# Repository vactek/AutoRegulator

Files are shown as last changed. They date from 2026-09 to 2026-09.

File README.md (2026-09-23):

# AutoRegulator

AutoRegulator is an Arduino Nano or NanoBLE powered suction regulator for vacbeds.
A relay is actuated based on a sensor and threshold - that's pretty much it.
It's designed to be inexpensive and easy to source parts for. 

It's very DIY - you could use it with a vacuum cleaner with a check valve, or a diaphragm pump.
This project is just in charge of switching a relay.

## WIP: TODO:
- finish sourcing links
- upload schematic and hardware build guide (maybe do a pcb, it's not that many wires to solder though)
- organize my 500 line main into separate files

## Features

- Automatic calibration to your elevation
- Settable suction level
- LED feedback

### NanoBLE only features

- Serial console with statistics
- coming soon? BLE functionality / [buttplug.io](https://github.com/buttplugio) integration (I have a separate working prototype, just have to integrate it)
- coming soon? pulsing/pattern playback functionality (may require additional hardware to increase venting rate)

### Safety features

This device isn't intended to be used alone, it's not safe, ***DO NOT*** do it.
We can't make any claims about safety, even if you build and use the project as intended.
In the rare case that something goes wrong, like, a lightning strike, we've tried to include as many safety features as reasonable:
  - shuts down on power loss or reset, which disables suction
  - requires external input (turn dial all the way to the left) upon reboot before starting
  - automatic shutdown if sensor read fails
  - automatic shutdown after 1 hour

...but you should not rely on any of these. Ever. This isn't enterprise industrial control software, it's DIY hardware, and ultimately, it's up to the operator of the machine to decide how to use this! *Even* having a supervisor may not be enough, and we actually recommend using [an entirely separate timer-controlled outlet](https://www.amazon.com/s?k=timer+controlled+outlet) in *addition*, to interrupt power to your pump after an hour.
(I'm not liable or responsible for the irresponsible use of this considerably irresponsible firmware written by idiots)

## Build Guide

### Electronics BOM with Sourcing (US)

 - Arduino Nano, or clone
 - Honeywell absolute pressure sensor breakout board
   - (preferred) Adafruit: https://www.adafruit.com/product/3965
   - (alternative) DigiKey: https://www.digikey.com/en/products/detail/adafruit-industries-llc/3965/9658071
   - (alternative, more expensive as shipping is bundled into price) Amazon: https://a.co/d/0icpQsJ6
 - Isolated relay module
   - (alternative) Amazon: https://a.co/d/0h9XaJEC
 - RGB Potentiometer
   - (preferred) Adafruit: https://www.adafruit.com/product/6387
   - (alternative) DigiKey: https://www.digikey.com/en/products/detail/adafruit-industries-llc/6387/27545875
   - If you'd like, you can use a plain linear rotary pot (10k ideally) and a single WS2812B-compatible LED
 - Solderable FR4 Protoboard - 70x90mm recommended
 - Female pin headers (optional, but makes swapping things out a lot easier while soldering)
 - 0.1uF ceramic capacitor (THT, optional, filter power input to relay board)

You may need some other things, such as:
 - Electrical tape
 - Pliers, screws
 - Soldering iron w/ fine solder
 - Wire (I used solid core 18AWG)
 - A screwdriver
 - And importantly, a wiring solution for whatever you connect the relay to. May require lever nuts, ferrules, etc.

### 3D Printed Parts (SLA)

- [Sensor to 3/16" tubing adapter](/models/AdafruitSensorToTubing.stl) (requires heatset inserts, and 2 2.5mmx8 SHCS screws)
- 3/16" tubing to PVC adapter (todo:link, other PVC size variants)
- 3/16" tubing break-out block

- You'll also want a case, but depending on where you mount the parts on the protoboard, it's going to be different.

### Assembly

- **NOTICE**: The Honeywell pressure sensor, and the breakout board by extension, is *extremely* fragile.
Even soldering the pin headers for too long can overexpose it to heat and cook it.
Giving it 5V on the 3Vo pin will instantly fry it.
Giving the regulator more than ~9V will instantly boil it.
SDA/SCL can accept at *most* whatever you give the regulator thanks to the level shifter.
Double check your wiring at every stage and before power on.

- **NOTICE**: AC Power is dangerous.

- Pinouts for supported boards

| Arduino Nano Pin | Arduino Nano33BLE Pin | Connect To | 
|---|---|---|
| A1 | A1 | Potentiometer center | 
| A2 | A2 | Neopixel Data In |
| A4 (SDA) | A4 (SDA) | Sensor SDA |
| A5 (SCL) | A5 (SCL) | Sensor SCL |
| A7 | A7 | Relay input |
| 5V | 3V3 | Potentiometer V+ |
| 5V | 3V3 | Neopixel VCC |
| 5V | 3V3 | Sensor Vin |
| Vin/VBUS | Vin/VBUS | Relay DC+ |
| GND | GND | Relay DC- |
| GND | GND | Sensor GND |
| GND | GND | Neopixel GND |
| GND | GND | Potentiometer V- |

---

| Relay Pin | Connect To |
|---|---|
| COM | User defined, e.g, AC neutral |
| NO | User defined, e.g, AC live |
| NC | **Nothing** |

---

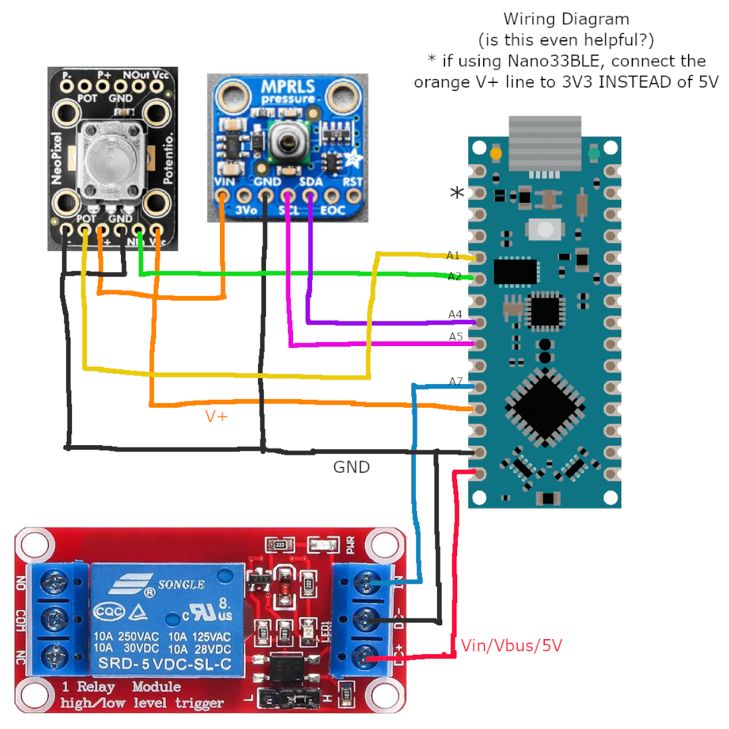
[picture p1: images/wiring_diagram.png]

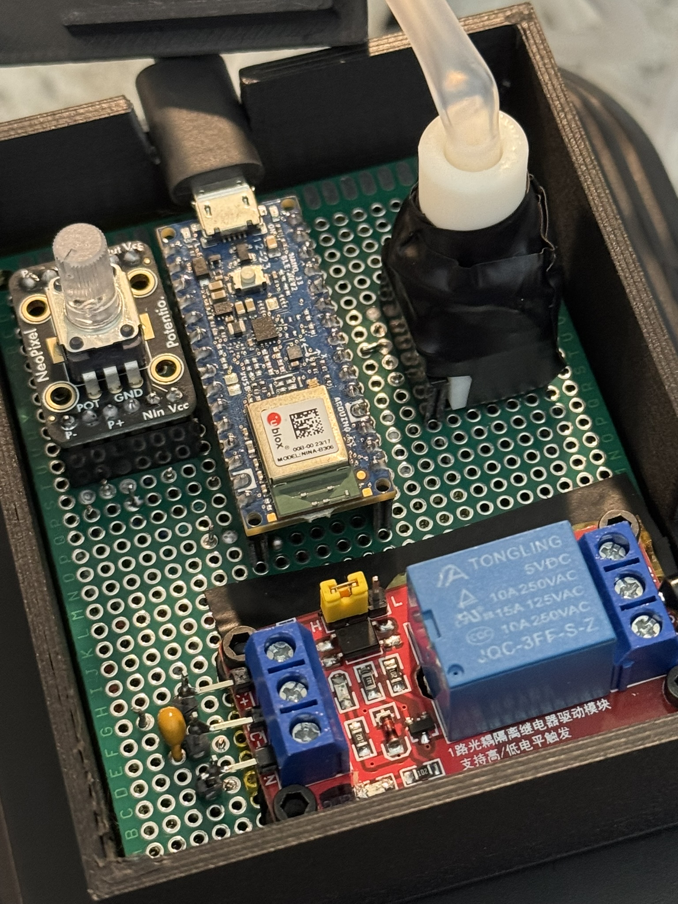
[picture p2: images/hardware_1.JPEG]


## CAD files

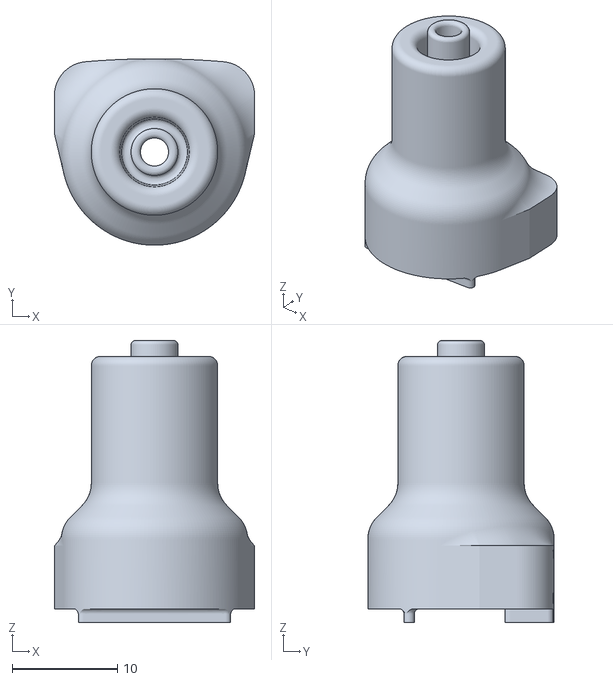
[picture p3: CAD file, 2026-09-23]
models/AdafruitSensorToTubing.stl
19.0 x 17.7 x 26.8

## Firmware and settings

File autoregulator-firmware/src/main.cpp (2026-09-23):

/**
  AutoRegulator Firmware for Arduino Nano / Nano33BLE
  
  We toggle a relay based on a sensor reading and threshold, set by a knob.

  2026
  
  Tip: Flash a DEV_ version to wait-for-serial

*/

#include <Arduino.h>
#include <Wire.h>
#include <Adafruit_MPRLS.h>
#include <Adafruit_NeoPixel.h>

#include "user_config.h"
#include "system_constants.h"

#include "app_debug.h"
#include "util.h"


// ### GLOBALS

// peripheral objects
Adafruit_NeoPixel g_neopixel(NUM_NEOPIXELS, PIN_NEOPIXEL, NEO_GRB + NEO_KHZ400);
Adafruit_MPRLS g_mpr25 = Adafruit_MPRLS(PIN_SENSOR_MANUAL_RESET, -1, MPR_PSI_MIN, MPR_PSI_MAX, MPR_factoryDefault_Omin, MPR_factoryDefault_Omax, MPR_Kfactor); // no rst/eoc

// vars
float calibration_ref_psi = PSI_ATMOSPHERIC;
float last_known_psi      = 0.0; // ONLY used for stats
// ONLY set this by enableSuction/disableSuction functions!
// ONLY read this for controlling LEDs!
bool isSuctionActive     = false;
float targetPressure     = 99999; // used by control system, AND for stats. units mbar
float potentiometerValue = 0.0;   // pot 0.0 - 1.0
// stats
uint32_t started_this_pull_at       = 0;    // if 0, we can assume we haven't started a pull down, but it's better to check isSuctionActive to be sure.
bool waiting_for_inital_pulldown    = true; // turns false the first time the target is reached
uint32_t first_pulldown_achieved_at = 0;
uint32_t this_pulldown_achieved_at  = 0; // also used for LED animation upon pulldown
// these vars are the number of counts spent "pulling down" a vacuum in the main loop
// and the total counts where the target pressure is met while in the main loop, respectively
// where one count occurs during one loop
uint32_t vac_duty_on_post_pulldown  = 0;
uint32_t vac_duty_off_post_pulldown = 0;

// elapsed-timers used by multiple functions
uint32_t time_of_last_mech_change = 0;
uint32_t time_since_last_mech_change() { return millis() - time_of_last_mech_change; }

// ### FUNCTIONS

void led_heartbeat() {
    // simple check if main loop is running. 0x20 -> brightness
    analogWrite(LED_BUILTIN, millis() % HEARTBEAT_PERIOD > (HEARTBEAT_PERIOD >> 1) ? 0x20 : LOW);
}

void configure_pins() {

    pinMode(LED_BUILTIN, OUTPUT);
    digitalWrite(LED_BUILTIN, LOW);

    pinMode(PIN_RELAY, OUTPUT);
    digitalWrite(PIN_RELAY, (MECHANICAL_ACTIVE_LEVEL == HIGH) ? LOW : HIGH);

    pinMode(PIN_NEOPIXEL, OUTPUT);
    pinMode(PIN_POTENTIOMETER, INPUT);

    // todo: dynamically (or statically if it's possible)
    // force the ADC resolution to 10 bits
    // in a way that works on all supported boards
}

bool userInputValid() {
    // true if an input is asserted; does not sample the adc, so you must call update_pot_val() first.
    return potentiometerValue > POT_LOWER_CUTOFF_PERCENT;
}

float get_single_pot_value() { 
    // just read the ADC, doesn't touch global state
    return mapfloat(analogRead(PIN_POTENTIOMETER), 0, AR_ADC_MAX, 0.0, 1.0); 
}

void disableSuction() {
    // (ideally) no effect if suction already disabled
    uint8_t state_prev = digitalRead(PIN_RELAY);
    uint8_t state_new  = (MECHANICAL_ACTIVE_LEVEL == HIGH) ? LOW : HIGH;
    digitalWrite(PIN_RELAY, state_new);
    isSuctionActive = false;
    if (state_new != state_prev) {
        time_of_last_mech_change = millis();
        started_this_pull_at     = 0;
    }
}

void disableSuctionFS() {
    // immediately disable suction, none of the fluff
    digitalWrite(PIN_RELAY, !(MECHANICAL_ACTIVE_LEVEL));
}

void enableSuction() {
    // no effect if suction already enabled
    // enables suction as soon as possible
    // only held up for mechanical wear reasons
    uint8_t state_prev = digitalRead(PIN_RELAY);
    uint8_t state_new  = (MECHANICAL_ACTIVE_LEVEL == HIGH) ? HIGH : LOW;

    if (state_new != state_prev) {
        while (time_since_last_mech_change() <= (float(MILLIS_PER_SEC) / MECHANICAL_MAX_HZ)) {
            // while in this spin, we still want to check the potentiometer in case the user turns it back off
            // don't replace this with !userInputValid, we actually have to poll it ourselves
            // the global isn't updated, and we don't want to take an average.
            if (get_single_pot_value() < POT_LOWER_CUTOFF_PERCENT) {
                disableSuction();
                return;
            }
        }
        time_of_last_mech_change = millis();
        started_this_pull_at     = time_of_last_mech_change;
    }
    digitalWrite(PIN_RELAY, state_new);
    isSuctionActive = true;
}

void update_pot_val() {
    // updates the global variable
    uint32_t running_total = 0;
    for (unsigned k = 0; k < POT_SAMPLE_SZ; k++) {
        running_total += analogRead(PIN_POTENTIOMETER);
        // let's not complicate it further, and pretend that analogRead is instantaneous
        delayMicroseconds((MICROS_PER_MILLI * POT_SAMPLE_DELAY) / POT_SAMPLE_SZ);
    }

    float avg          = running_total / POT_SAMPLE_SZ;
    potentiometerValue = mapfloat(avg, 0, AR_ADC_MAX, 0.0, 1.0);
}

void neopixel_show_i2c_rate_limited() {
    // calls g_neopixel.show but only if we didn't call it in the last 2ms
    // todo: the actual rate limit, lmao
    g_neopixel.show();
}

void neopixel_show_color(uint32_t c) {
    g_neopixel.fill(c);
    g_neopixel.setBrightness(LED_BRIGHTNESS_PERCENT * 0xFF);
    neopixel_show_i2c_rate_limited();
}

void neopixel_flash_color(uint32_t c) {
    // non-blockingly flash a color
    static unsigned period = MILLIS_PER_SEC / LED_RAPID_FLASH_HZ; // ms

    if ((millis() % period) > (period >> 1)) {
        g_neopixel.fill(c);
        g_neopixel.setBrightness(LED_BRIGHTNESS_PERCENT * 0xFF);
    } else {
        g_neopixel.clear();
    }
    neopixel_show_i2c_rate_limited();
}

void _on_fail(void) {
    // ! invoke with EXIT_FAILURE_FN() - NOT DIRECTLY !
    // function to run when something goes wrong.
    disableSuction();
    DEBUGLN(F("on_fail called, halting"));
    while (true) {
        neopixel_flash_color(COLOR_ERROR);
    }
}
#define EXIT_FAILURE_FN()                                                                                                                                                                                                                      \
    {                                                                                                                                                                                                                                          \
        disableSuctionFS();                                                                                                                                                                                                                    \
        TIMESTAMPLN();                                                                                                                                                                                                                         \
        _on_fail();                                                                                                                                                                                                                            \
    }

void periodicStatsPrint() {
#ifdef CAN_STORE_MANY_STRINGS
    static uint32_t loopcounter        = 0;
    static uint32_t time_of_last_print = 0;
    loopcounter++;
    if ((millis() - time_of_last_print) < PRINTERVAL) {
        return;
    }

    TIMESTAMPLN();

    DEBUG("> Superloop ARR: ");
    DEBUG(float(loopcounter) / ((millis() - time_of_last_print) / float(MILLIS_PER_SEC)));
    DEBUGLN(" Hz");
    loopcounter = 0;

    DEBUG("> Raw pressure (Psi): ");
    DEBUGLN(last_known_psi, 2);

    DEBUG("> Estimated Suction (mbar): ");
    float curSuction = (calibration_ref_psi - last_known_psi) * PSI_TO_MBAR; // mbar
    curSuction       = max(0.0f, curSuction);                                // clip
    DEBUG(curSuction, 2);
    static float ambient_mbar = calibration_ref_psi * PSI_TO_MBAR; // I know the controller does this calculation too, not worth making it global though
    float targetSuction       = ambient_mbar - targetPressure;
    if (isSuctionActive) {
        DEBUG(" (");
        DEBUG(100.0 * curSuction / targetSuction, 1);
        DEBUG("% of target, ");
        DEBUG(100.0 * curSuction / SUCTION_MAX_MBAR, 1);
        DEBUGLN("% of maximum)");
    } else {
        DEBUGLN();
    }

    DEBUG("> State: ");
    if (isSuctionActive) {
        if (waiting_for_inital_pulldown) {
            DEBUG("pulling down for ");
        } else {
            DEBUG("assisting pressure for ");
        }
        DEBUG((millis() - started_this_pull_at) / float(MILLIS_PER_SEC), 1);
        DEBUGLN("s");
    } else if (userInputValid()) {
        DEBUGLN("pressure holding on its own");
    } else {
        DEBUGLN("shut off");
    }

    if (waiting_for_inital_pulldown) {
        DEBUGLN("> Duty cycle will show after initial pulldown");
    } else {
        if (vac_duty_off_post_pulldown == 0) {
            vac_duty_off_post_pulldown = 1; // prevent divide by zero in edge case
        }
        DEBUG("> Duty cycle (since pulldown at t=");
        DEBUG(first_pulldown_achieved_at);
        DEBUGLN("):");
        DEBUG((100 * vac_duty_on_post_pulldown) / (vac_duty_on_post_pulldown + vac_duty_off_post_pulldown));
        DEBUGLN("%");
    }

    DEBUG("> Time remaining before operator is required to reboot: ");
    DEBUG((BACKUP_TIMER_MS - millis()) / float(MILLIS_PER_MINUTE), 1);
    DEBUGLN(" minutes");

    time_of_last_print = millis(); // put last so that long serial prints dont affect reported frequency as much
#endif
}

void doNeopixelColorBasedOnPot() {
    const int num_flashes_upon_success = 3;
    bool shouldPulsate                 = isSuctionActive;
    if (!userInputValid()) {
        g_neopixel.clear();
        neopixel_show_i2c_rate_limited();
        return;
    }

    // fancy magic color mapping from green to red
    g_neopixel.fill(g_neopixel.ColorHSV(mapfloat(potentiometerValue, POT_LOWER_CUTOFF_PERCENT, 1.0, (0.36 * 65535), (0.0 * 65535))));

    // stage 2: set brightness, based on activity
    // pulsate while suction active
    // blink green when pulldown achieved
    // solid when vacuum is holding
    if (shouldPulsate) {
        // we use both halves of the sine wave
        // so there's an invisible divided by two and times two that cancel out
        // g_neopixel.gamma8( looked bad
        g_neopixel.setBrightness(LED_BRIGHTNESS_PERCENT * 0xFF * abs(sinf(LED_FLICKER_HZ * PI * millis() / float(MILLIS_PER_SEC))));
    } else {
        if ((millis() - this_pulldown_achieved_at) <= (MILLIS_PER_SEC * num_flashes_upon_success / LED_RAPID_FLASH_HZ)) {
            // detour, we want a completely different output driver
            neopixel_flash_color(COLOR_SUCCESS);
            return;
        }
        g_neopixel.setBrightness(LED_BRIGHTNESS_PERCENT * 0xFF);
    }

    neopixel_show_i2c_rate_limited();
}

float get_mpr_sample() {
    // return a sample as soon as possible, blocks if called too rapidly
    // units set at object instantiation, should be PSI since K=1
    static uint32_t time_of_last_mpr_read = 0;
    while ((millis() - time_of_last_mpr_read) <= (float(MILLIS_PER_SEC) / MPR_MAX_HZ)) {
        yield();
    }
    delay(1); // we can yeep for a sec
    float sample          = g_mpr25.readPressure();
    time_of_last_mpr_read = millis();
    last_known_psi        = sample; // for statistics, do not use elsewhere
    time_of_last_mpr_read = millis();
    if (isnanf(sample)) {
        EXIT_FAILURE_FN();
    }
    return sample;
}

float get_mpr_average(unsigned n) {
    // sample the sensor a handful of times and return the average PSI
    if (n <= 0) {
        return 0.0f;
    }

    float accumulator = 0;
    for (unsigned k = 0; k < n; k++) {
        accumulator += get_mpr_sample();
    }
    return accumulator / n;
}

void calibrate_and_check() {
    // get the actual, local pressure today for accuracy
    DEBUGLN("Calibrating");
    uint32_t calibration_start = millis();
    disableSuction();
    // todo: open vents here if they exist
    while (millis() < (calibration_start + CALIBRATION_VENT_TIME_MS)) {
        neopixel_flash_color(COLOR_PROCESSING_WAIT);
    }

    // check if pressure reading is stable
    float accumulator = 0;
    float min         = 9999;
    float max         = -9999;
    for (int k = 0; k < STABILITY_CHECK_SAMPLES; k++) {
        float s = get_mpr_sample();
        DEBUGLN(s);
        uint32_t stab_sampl_start = millis();
        while (millis() < (stab_sampl_start + STABILITY_CHECK_TIME_MS / STABILITY_CHECK_SAMPLES)) {
            neopixel_flash_color(COLOR_PROCESSING_WAIT);
        }
        accumulator += s;
        if (s < min) {
            min = s;
        }
        if (s > max) {
            max = s;
        }
    }
    float range         = max - min;
    calibration_ref_psi = accumulator / STABILITY_CHECK_SAMPLES;

    DEBUG("Local pressure is ");
    DEBUG(calibration_ref_psi, 2);
    DEBUGLN("psi");

    DEBUG("Stability test range: ");
    DEBUGLN(range);
    if (range > STABILITY_CHECK_MAX_DEVIATION) {
        DEBUG("calibration fail: too wide of range: ");
        DEBUG(max);
        DEBUG(" - ");
        DEBUG(min);
        DEBUG(" = ");
        DEBUGLN(range);
        EXIT_FAILURE_FN();
    }

    if (calibration_ref_psi > PSI_ATMOSPHERIC_MIN) {
        DEBUGLN("Done");
    } else {
        DEBUGLN("calibration fail: atmospheric minimum");
        EXIT_FAILURE_FN();
    }
}

void wait_for_zero_input() {
    // called at the end of setup before the main loop
    // requires the user to turn the potentiometer down all the way for a short time
    // + cool little lighting bit
    const uint32_t must_stay_off_for = 200; // ms
    DEBUGLN("To start, turn dial all the way left, then to the right");
    while (get_single_pot_value() >= POT_LOWER_CUTOFF_PERCENT) {
        neopixel_flash_color(COLOR_AWAITING_USER);
    }
    neopixel_show_color(COLOR_NONE_OFF);
    while (true) {
        bool canBreak         = true;
        uint32_t t_zero_start = millis();
        while ((millis() - t_zero_start) < must_stay_off_for) {
            if (get_single_pot_value() >= POT_LOWER_CUTOFF_PERCENT) {
                canBreak = false;
                break;
            }
        }
        if (canBreak) {
            break;
        }
    }
    DEBUGLN("Ready");
    while (get_single_pot_value() < POT_LOWER_CUTOFF_PERCENT) {
        neopixel_show_color(COLOR_AWAITING_USER);
    }
}

void bang_bang_controller() {
    // try to keep variables in mbar!
    static float ambient_mbar = calibration_ref_psi * PSI_TO_MBAR;

    float currentPressure = get_mpr_average(SENSOR_READINGS_PER_CONTROL_LOOP) * PSI_TO_MBAR;
    // similarly to led control, if below a threshold, we disable our output
    if (!userInputValid()) {
        disableSuction();
        return;
    }
    targetPressure       = ambient_mbar - mapfloat(potentiometerValue, POT_LOWER_CUTOFF_PERCENT, 1.0, SUCTION_MIN_MBAR, SUCTION_MAX_MBAR);
    float lowest_allowed = targetPressure - SUCTION_HYSTERESIS;

    if (currentPressure <= lowest_allowed) {
        // target reached!
        disableSuction();
        this_pulldown_achieved_at = millis();
        // uncomment these for immediate tuning feedback
        // DEBUGLN(currentPressure); // pressure in mbar
        // DEBUGLN(calibration_ref_psi * PSI_TO_MBAR - targetPressure); // current suction in mbar
        //
        if (waiting_for_inital_pulldown) {
            waiting_for_inital_pulldown = false;
            first_pulldown_achieved_at  = millis();
        }
    }
    if (currentPressure >= targetPressure) {
        enableSuction();
    }
}

void setup() {
    // ## early setup
    Wire.begin();
    configure_pins();

    Serial.begin(SERIALBAUD);
#ifdef VERSION_DEV
    while (!Serial) {
        yield();
    }
#endif
    delay(SERIAL_ENUMERATION_DELAY);
    DEBUGLN("Serial Connected!");
    
    // ## mid setup
    bool init_neopixel_success = g_neopixel.begin();
    if (!init_neopixel_success) {
        DEBUGLN("INIT FAIL: NEOPIXELS");
        DEBUGLN("This should never happen!");
    }
    bool init_mpr_success = g_mpr25.begin(0x18, &Wire);
    if (!init_mpr_success) {
        DEBUGLN("INIT FAIL: MPR");
        DEBUGLN("The pressure sensor sometimes requires a power or reset cycle.");
    }
    if (!init_neopixel_success || !init_mpr_success) {
        DEBUGLN("One or more inits failed, halting.");
        EXIT_FAILURE_FN();
    }

    // ## late setup
    calibrate_and_check();
    wait_for_zero_input();
}

void loop() {
    led_heartbeat();

    // core functionality
    update_pot_val();
    bang_bang_controller();
    doNeopixelColorBasedOnPot();
    if (millis() > BACKUP_TIMER_MS) {
        EXIT_FAILURE_FN();
    }

    // some stats collection
    if (!waiting_for_inital_pulldown && userInputValid()) {
        if (isSuctionActive) {
            vac_duty_on_post_pulldown++;
        }
        if (!isSuctionActive) {
            vac_duty_off_post_pulldown++;
        }
    }
    periodicStatsPrint();
}

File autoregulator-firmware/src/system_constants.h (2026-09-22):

#pragma once

#include <Arduino.h>

// *** AUTO REGULATOR SYSTEM CONFIGURATION *** //

// --- Hardware ---

#define AR_ADC_MAX      (1023)  // don't change this
#define AR_ADC_BITS     (10)    // don't change this: nano 328 default

// --- Limits ---
#define BACKUP_TIMER_MS    (3600000UL) // 1h in ms. machine will shut off at this time. not for solo; it's if the operator is struck by lightning.

const float PSI_ATMOSPHERIC               = 14.6959; // only used if calibration is ever bypassed for some reason
const float PSI_ATMOSPHERIC_MIN           = 10.20;   // 10kft@22C@11atm, used as a check in calibration, won't start if below this
const float STABILITY_CHECK_MAX_DEVIATION = 0.70;    // I get values around 0.02-0.05 sometimes, but up to 0.3 on occasion. this margin is probably generous
const int STABILITY_CHECK_SAMPLES         = 100;
const uint32_t STABILITY_CHECK_TIME_MS    = 2000;


// --- World Constants ---
const float PSI_TO_MBAR             = PSI_to_HPA;
const float MPR_MAX_HZ              = 160.0;
const float MPR_PSI_MIN             = 0.0;
const float MPR_PSI_MAX             = 25.0;
const float MPR_factoryDefault_Omin = 10.0;
const float MPR_factoryDefault_Omax = 90.0;
const float MPR_Kfactor             = 1.0; // set to one to force output in PSI

const uint32_t MILLIS_PER_SEC       = 1000;
const uint32_t MICROS_PER_MILLI     = 1000;
const uint32_t MILLIS_PER_MINUTE    = 60000;


// --- Application Config ---

#define SERIAL_ENUMERATION_DELAY         (100u) // way shorter than esp32 sweet
#define HEARTBEAT_PERIOD                 (750u)
#define PRINTERVAL                       (1000u) // stats printing period
#define POT_SAMPLE_SZ                    (10u)   // adc samples for pot averaging
#define POT_SAMPLE_DELAY                 (10u)   // total (minimum) time in ms over which to take the samples
#define POT_LOWER_CUTOFF_PERCENT         (0.05f) // pot will be considered switched off below this precentile of its range
#define LED_BRIGHTNESS_PERCENT           (0.32f) // neopixel brightness
#define LED_RAPID_FLASH_HZ               (5.0f)  // flashing rate while calibrating
#define LED_FLICKER_HZ                   (0.80f) // flickering rate while machine active
#define SENSOR_READINGS_PER_CONTROL_LOOP (4u)    // integer, readings are averaged, 2-8 seems the right balance
#define NUM_NEOPIXELS                    (1u)
#define CALIBRATION_VENT_TIME_MS         (1000u)

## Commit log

2026-09-21 add wiring diagram, pinout
2026-09-21 add distinction between 'can serial print' and 'must wait for serial'
2026-09-21 add green led flash every time target pressure is reached
2026-09-23 complete a couple of todos
2026-09-23 add sensor reset pin option to config
